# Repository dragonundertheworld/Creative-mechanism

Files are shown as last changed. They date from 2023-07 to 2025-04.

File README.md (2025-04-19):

# Hexapod Carrying Robot

A six‑legged, material‑transporting robot designed and built as part of the “Mechanism Creativity Design & Practice” course at the University of Electronic Science and Technology of China. This project combines a biomimetic four‑bar leg mechanism with a sequential gearbox and a cam‑driven dumping mechanism to achieve stable walking, three‑speed drive, and controlled payload discharge.

---

## Table of Contents

- [Hexapod Carrying Robot](#hexapod-carrying-robot)
  - [Table of Contents](#table-of-contents)
  - [Features](#features)
  - [Mechanical Design](#mechanical-design)
    - [Leg Mechanism](#leg-mechanism)
    - [Tripod Gait Coordination](#tripodgait-coordination)
    - [Sequential Gearbox](#sequential-gearbox)
    - [Payload Dumping Mechanism](#payload-dumping-mechanism)
  - [Performance Specifications](#performance-specifications)
  - [Bill of Materials](#bill-of-materials)
  - [Assembly Instructions](#assembly-instructions)
  - [Motion Simulation \& Testing](#motion-simulation--testing)
  - [Operation Guide](#operation-guide)
  - [Known Issues \& Improvements](#known-issues--improvements)
  - [Future Work](#future-work)
  - [Contact](#contact)

---

## Features

- **Stable Tripod Gait**  
  - Each side consists of front and rear four‑bar linkages, with a centrally driven auxiliary leg to form a three‑point support at all times.  

- **Three‑Speed Drive + Neutral**  
  - Inspired by motorcycle sequential transmissions. Three selectable gear ratios (1:2, 1:1, 2:1) plus neutral for dumping.  

- **Cam‑Driven Dump Mechanism**  
  - When gearbox is in neutral, power is diverted to a cam and follower rod which tilts the payload bucket through a 60° swing.  

- **Modular & Lightweight**  
  - All leg members are assembled from standard aluminum rods and connectors. Custom 3D‑printed dog‑teeth and shafts ensure proper clutch engagement.  

---

## Mechanical Design

### Leg Mechanism

- **Structure**: Two four‑bar linkages per leg (rear crank + rocker driving front rocker), plus an auxiliary “middle” foot bar.  
- **Kinematic Analysis**:  
  - Four‑bar lengths: Crank = 63 mm, Rocker A = 95 mm, Rocker B = 110 mm, Frame = 77 mm (satisfies Grashof condition).  
  - Produces a lifted step height of ~113 mm and horizontal stride of ~146 mm per cycle.  

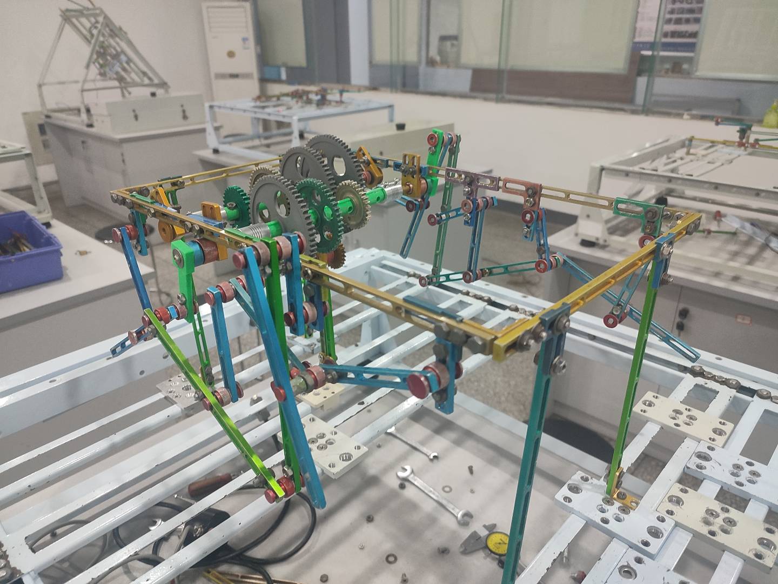
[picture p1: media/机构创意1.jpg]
Leg Mechanism


### Tripod Gait Coordination

- **Phasing**:  
  - Rear cranks on left/right sides set 180° apart.  
  - Middle auxiliary legs mirror each four‑bar’s motion to synchronize three legs in support and three in swing.  
- **Degrees of Freedom**:  
  - F = 3n – 2·Pl – Ph = 1 (single actuation drives one full gait cycle).

### Sequential Gearbox

- **Layout**: Two parallel shafts (input & output), three sliding gears with dog‑teeth collars, one neutral position.  
- **Gear Ratios**:  
  1. First Gear (1:2): 30‑tooth ⟷ 60‑tooth  
  2. Second Gear (1:1): 45‑tooth ⟷ 45‑tooth  
  3. Third Gear (2:1): 60‑tooth ⟷ 30‑tooth  
  4. Neutral: Intermediate slider dog engages secondary shaft’s lower idler gear to drive cam.  

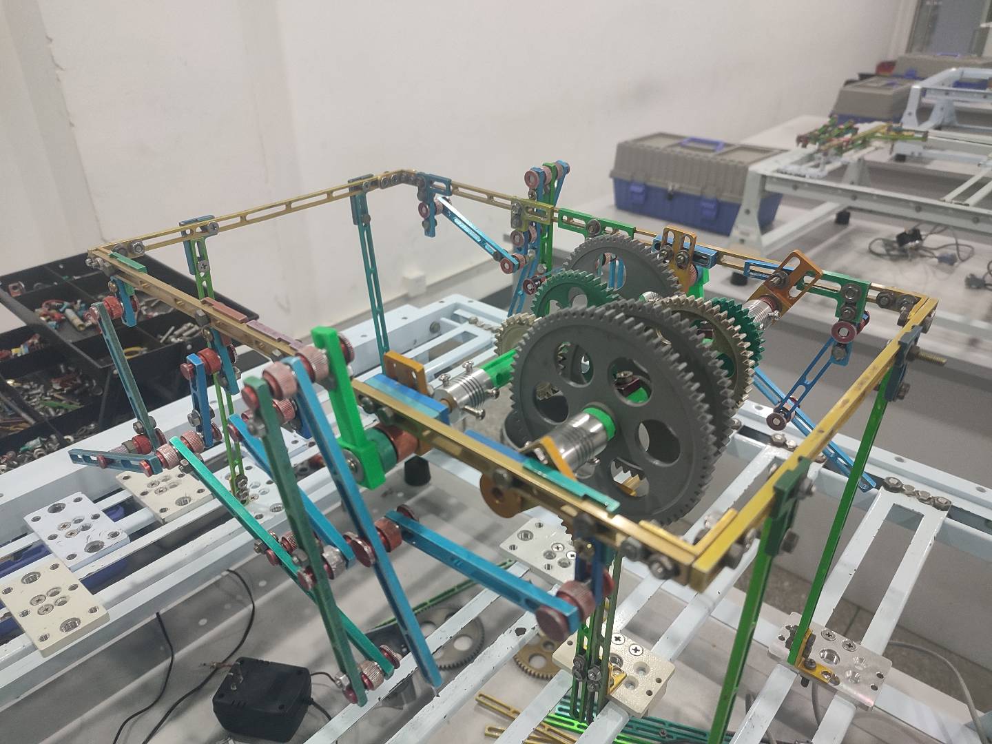
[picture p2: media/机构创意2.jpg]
Gearbox Principle


### Payload Dumping Mechanism

- **Cam‑Follower Design**:  
  - In neutral, power is routed via belt and idler gear to a cam.  
  - A follower rod presses on the cam profile, driving a bucket linkage through 0–60° swing.  
- **Cycle Time**: ~4 s per dump stroke.

---

## Performance Specifications

| Parameter | Value |
|---|---|
| Motor Speed | 30 rpm |
| Leg Cycle Time (30 rpm) | 2.0 s |
| Foot‑Ground Contact Time | 0.6 s |
| Step Length | 146 mm |
| Maximum Lift Height | 113 mm |
| Linear Speeds | 7.3 cm/s (1st), 14.6 cm/s (2nd), 29.2 cm/s (3rd) |
| Dump Angle | 60° |
| Dump Cycle Time | 4 s |

---

## Bill of Materials

| Item | Specification | Qty |
|---|---|-----|
| Aluminum Rods & Connectors | Standard Meccano‑style | 50+ |
| Gears | 30, 45, 60 teeth, m = 1.5 | 6 |
| Custom Dog‑Teeth Collars | 3D‑printed, m = 1.5 | 3 |
| Motor | 30 rpm, 12 V DC | 1 |
| Bearings & Bushings | φ 5–φ 10 mm | 20  |
| Cam & Follower Components | Steel rod & plate | 1 set |
| Buckets & Linkage Plates | Acrylic/PLA | 1 set |
| Fasteners & Limit Nuts | M3–M5 bolts & nuts | 200 |
| Belts & Pulleys | Timing belt, idler pulleys| 1 set |
| Rotary Encoder (optional) | 360 P/R | 2 |

---

## Assembly Instructions

1. **Leg Sub‑Assembly**  
   - Bolt four‑bar linkages together; use limit‑nuts on slotted joints to prevent sliding.  
   - Install auxiliary foot bars at mid‑link hinge points.  
   - Mount front and rear leg pairs symmetrically on left/right frames.  

2. **Gearbox & Motor**  
   - Mount motor to input shaft gear; align dog‑tooth collars on output shaft.  
   - Test each gear position for smooth engagement.  

3. **Dump Mechanism**  
   - Fit cam on lower idler shaft; attach follower rod to bucket pivot.  
   - Route belt from neutral‑position gear to cam pulley.  

4. **Chassis & Frame**  
   - Build a tabletop‑frame fixture for stable walking tests.  
   - Secure all shafts in bearings; leave 0.5–1 mm play for tolerance.  

5. **Final Checks**  
   - Verify free rotation of all joints and gears in each position.  
   - Add washers or shims where necessary to eliminate binding.  

---

## Motion Simulation & Testing

- **Software**: SolidWorks Motion  
- **Test Protocol**:  
  - Drive rear crank at 30 rpm; record foot trajectories and contact time.  
  - Use angle sensors on motor and output shafts to compare theoretical vs. actual speeds.  
- **Results**:  
  - Average driven‑shaft speeds match expected gear ratios within ±5%.  
  - Outliers (3 in 1st gear, 5 in 2nd gear) filtered via 3σ rule; see `data_analysis.py`.

---

## Operation Guide

1. **Power On**: Connect 12 V DC to motor.  
2. **Select Gear**: Slide gearbox collar to desired position (1–2–3 or Neutral).  
3. **Start Walking**: Robot will walk in the selected speed.  
4. **Activate Dump**: Shift to Neutral, wait for cam cycle to complete bucket tilt, then return to walking mode.  
5. **Shutdown**: Shift to Neutral, remove power.

---

## Known Issues & Improvements

- **Joint Play**: Slotted connectors require limit nuts; consider custom printed joints for tighter fit.  
- **Gearbox Space**: Limited room for dog‑teeth—optimize collar length to restore four‑gear capability.  
- **Motor Coupling**: Soldered leads prone to intermittent contact—use a detachable connector.  

---

## Future Work

- **Lightweight Frame**: Replace aluminum rods with CNC‑cut PLA parts to reduce weight and improve precision.  
- **Integrated Clutch**: Implement a one‑way clutch for seamless in‑motion gear shifts.  
- **Autonomous Control**: Add microcontroller and gait‑planning algorithm for untethered operation.  
- **Sensor Fusion**: Integrate IMU and force sensors to adapt foot placement on uneven terrain.

---

## Contact

Project Team: Xuning Gou & Zhihan Cao  
Course Instructor: Prof. Ping Mu  
University of Electronic Science and Technology of China  
Mechanical & Electrical Engineering School  
Email: 1300464438@qq.com

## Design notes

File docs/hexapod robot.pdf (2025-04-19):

摘要

I

摘 要

足式机器人相较于轮式与履带机器人更能适应复杂的地形结构，在军事运 输、抗震救灾、残疾人辅助甚至星际探索等众多领域都有广阔的应用前景。我 们利用杆件设计腿部机构，采用齿轮组进行三档变速，并通过凸轮实现基本的 运载功能。通过课程，我们了解了足式机器人以及变速箱的基本原理，利用四 杆机构得到了较好的足部运动轨迹。

关键字：步行机器人、多足仿生机构、变速机构、运载机器人

目录

II

目 录

第 2 章 机构方案设计 | ？
2.1 方案一设计 | ？
2.2 方案二设计 | ？
2.3 方案比较及定型 | ？
第 3 章 机构设计计算 | ？
3.1 执行件运动设计 | ？
3.2 运动参数设计计算 | ？
3.3 构件参数设计计算 | ？
第 4 章 改进完善设计 | ？
4.1 制约方案实现的原因 | ？
4.2 改进完善 | ？
第 5 章 实验搭建与安装测试 | ？
5.1 机构模型搭建 | ？
5.2 搭建效果及运行结果 | ？
5.3 安装传感器测试 | ？
第 6 章 实验报告与数据分析 | ？
6.1 实验报告 | ？6.2
测试结果 | ？
6.3 数据分析 | ？
结束语 | ？
参考文献 | ？
附 录 | ？

机构创意设计及实践设计报告

3

### 第 1 章 引 言

1.1 工程背景

自从 1959 年第一台工程工业机器人在美国诞生以来，各种用途的机器人便

相继问世。多足仿生机器人由于拥有更高的运动灵活性和对特殊环境的适应性，

一直是研究的热点，在很多特殊的运用场景中都能看到他们的身影。例如，轮式

机器人和履带机器人在较为平稳的环境中速度快，能耗低。但在崎岖的环境中往

往会出现抖动严重的情况，所以在某些对平稳性要求较高的场景中难以达到最佳

效果。足部机器人利用腿部角度和高度的相互配合，可以很大程度的保持自己的

重心位置和平稳性，避免侧翻等危险情况的发生，同时也为路径的最优化选择带

来了更多可能性。

但是由于多足机器人腿部自由度高，也对机体的协调控制带来了巨大的挑

战。在运行过程中必须时刻考虑机体的平稳性，足部的落脚点等诸多因素，导致

它的结构设计和控制算法都尤其复杂。与自然界真实生物的机动性相比，还有很

大的差距。在本次实践中，我们从结构设计入手，得到足式机器人最基本的行走

机构。抛开复杂的控制算法，利用最基本的机械结构使机器人协调运动。虽然这

与最终的仿生机器人还相差甚远，但是却可以为足部构造的研究设计提供重要的

参考价值。

1.2 功能要求及指标

六足机器人又叫蜘蛛机器人，顾名思义，其原理借鉴了自然界中昆虫的运动

原理，机器人的腿部位于身体的两侧，并类似于蚂蚁，在前胸，中胸，后胸各有

一对足。问题的关键，在于两点。一是六条腿之间应该怎样相互配合让整体协调；

二是每条腿部应该如何运动以实现足部末端的运动轨迹。

对腿部之间的协调，我们提出了以下要求：

在整个过程中，机器人的运动尽可能的对称，机体在运行时起伏不能太大，

3

以满足平稳性。

六条腿部的运动效果要尽可能贴近生物的运动姿态。

六条腿之间的配合结构尽可能简洁，以减轻整体的重量。

对每条腿内部的运动，我们提出了以下要求：

腿部在地面支撑的时间应尽可能大于腿部悬空的时间，这有利于整体效率的

提升，对人来说：每一步足部在地面支撑的时间大致为周期的 60%，可以作为参

考。

希望足部的轨迹曲线中，接触地面的一段跨越的水平宽度尽可能大，以提高

行走的速度。

希望足部的轨迹曲线中。悬空时竖直跨越的高度尽可能高，以提高跨越障碍

的能力。

除基本的行走之外，我们希望机器人拥有变速和物料运输的能力。

其中：

变速功能：我们采用齿轮组的配合实现，通过改变齿轮的配合关系，得到不

同的变速比，在本次实验中，我们对机器人设计了四个档位，其中有三个档位用

于速度的调整，另外一个档位用于机器人停下时，物料的装配。

物料运输功能：我们采用基本的凸轮加顶杆的形式实现物料的倾倒动作。只

需要调整顶杆运动的高度，便可以调整物料倾倒的角度。

1.3 发展态势

六足机器人相较于其它多足机器人，有自己独特的优势。相较于两足机器人，

六足机器人更加稳定，不易翻倒。相较于四足机器人，六足机器人又有更大的承

载和工作能力。从国外的情况来看，六足机器人的技术越来越完善，应用场景也

越来越多样化。例如波士顿动力的 RHex 越野六足机器人、NASA 开发研制的

ATHLETE 全地形六足地外探测器、西班牙工业化研究自动所设计的用于排雷的

SILO-6 机器人等。我国的六足机器人虽然发展较晚，但已在迎头追赶国外的技

3

术，例如华中科大设计制造的“4+2”型六足机器人、北京理工大学设计的弓背

蚁机器人、上海交大自主研发的六足滑雪机器人等等。六足机器人正朝着智能化、

实用化、轻量化的方向蓬勃发展，目前适用于恶劣和特殊环境的六足机器人控制

和机械问题还没有得到完全解决，但可以预见未来它们将在人类的生活和工作中

扮演十分重要的角色。

3

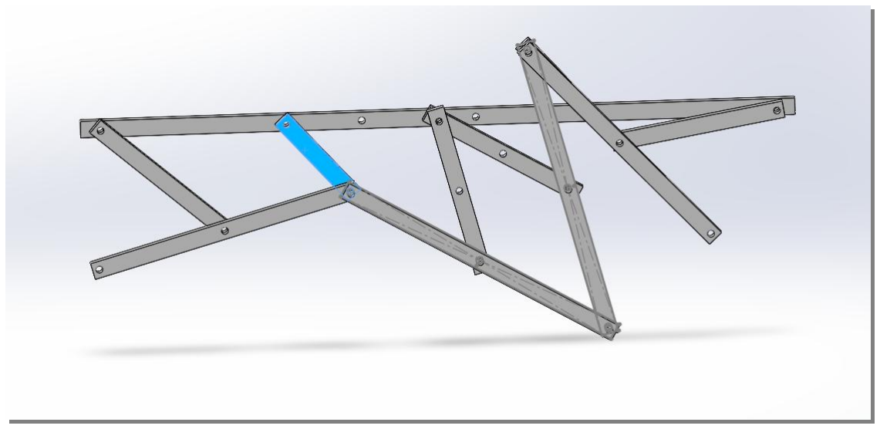
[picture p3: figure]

2

### 第 2 章 机构方案设计

2.1 方案一设计

功能原理：

步行机构

分为左右两条机械腿，每条机械腿由前后两个四连杆机构连接而成，当后面

的连杆机构被驱动时，其会将运动通过连接处同步不同相地传递至前面的连杆机

构，从而实现前后两只脚轮流接触地面。同时中间的连接处也连有一只脚，这种

结构所产生的步态称为三足步态[2]，这样的的设计可以使任意时刻都至少有 3 只

脚同时接触地面，且每个周期内的行进模式完全一致，因此运动更加平稳连贯。

变速机构

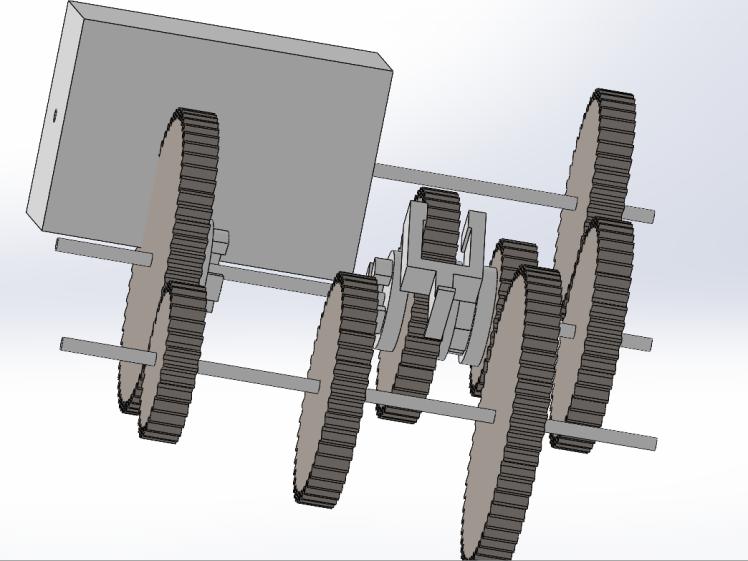
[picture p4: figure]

8

速度档位共有 4 档，分别对应变速比为 1：2，1：1，2：1 的三种齿轮组合

和空挡，通过移动可动齿轮使之与不同齿数的齿轮啮合来改变变速比。

物料运输机构：

当变速机构位于空挡状态下，可动齿轮与铲斗间接驱动齿轮啮合，并通过齿

条将运动传送传递至铲斗直接驱动齿轮，铲斗直接驱动齿轮带动凸轮旋转并通过

顶杆实现铲斗的抬升与下降的往复运动。

仿真搭建图：

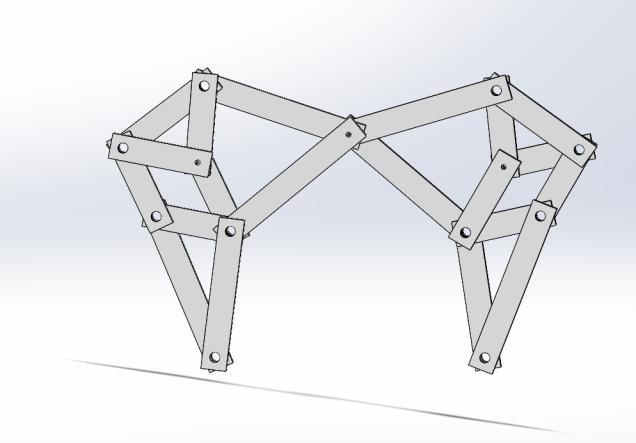
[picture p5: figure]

8

F 计算：

腿部 n=10,pl=13,ph=0, F1=3(n-1)-(2pl+ph)=27-26-0=1

变速箱：以 1：2 档为例：n=9,pl=9,ph=2, F1=3(n-1)-(2pl+ph)=24-20-2=1

物料运输机构：n=7,pl=5,ph=2, F1=3(n-1)-(2pl+ph)=12-10-3=1

2.2 方案二设计

功能原理

Strandbeests 是荷兰动感雕塑艺术家泰奥扬森发明的“风力仿生兽”，本方

案便是仿照其机构并进行设计。其由多条腿组成，每条腿上又分前腿和后腿，二

者通过铰链连接。电机驱动连接处绕轴旋转，运动通过杆件传递至足部。由于存

在多个杆件，其运动较为平稳。

机构简图

F 计算（一条腿）

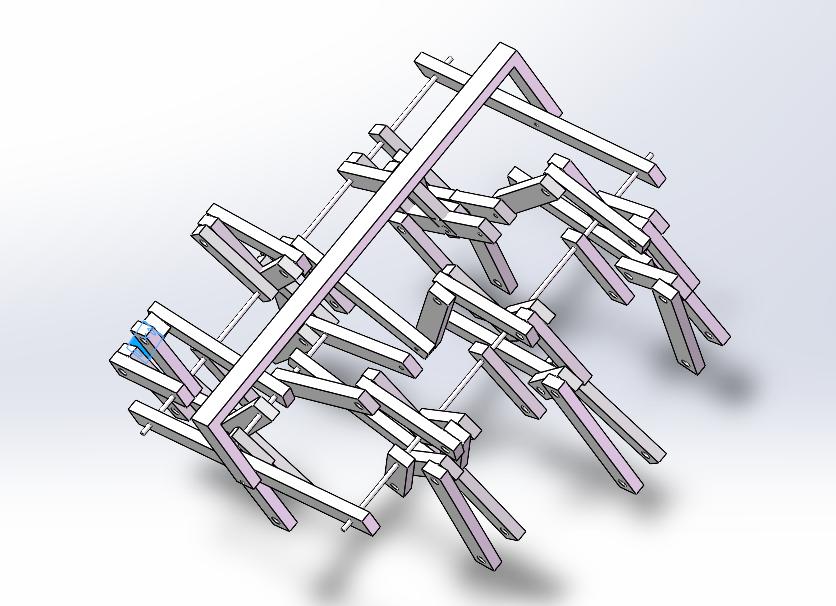
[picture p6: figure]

n=22,pl=31,ph=0, F2=3(n-1)-(2pl+ph)=63-62=1

2.3 方案比较

方案一与方案二两者相比相比，方案二结构更加复杂，具体表现为：①每条

腿所用杆件数量更多②腿数更多③腿之间的配合要求十分紧密。而且中空部分狭

小，放不下变速箱或铲斗等机构。故选择方案一。

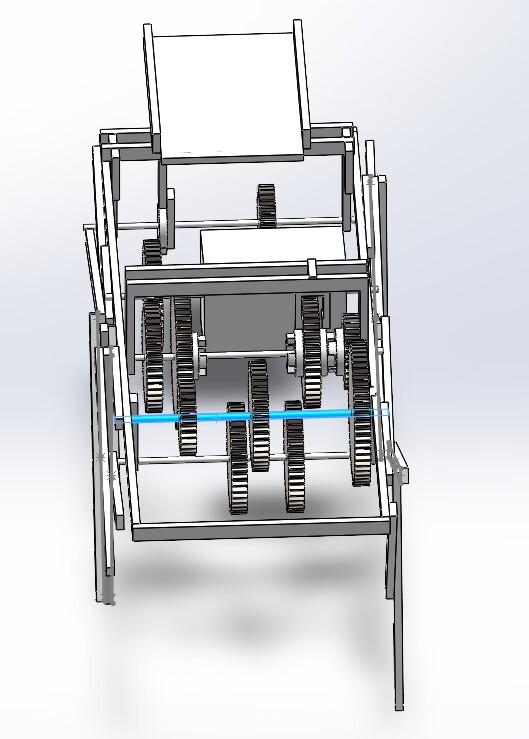
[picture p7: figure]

3

### 第 3 章 机构设计计算

3.1 执行件运动设计

足部和铲斗分别作为机构两个执行件，其中足部由四杆机构中的连杆末端构

成的主足和四杆机构之间的辅助足组成。主足的运动由四杆机构直接控制，而辅

组足则由前后四杆机构的两个曲柄驱动。铲斗则是被连接凸轮的顶杆控制俯仰的

角度，完成倾倒的动作。

如下图所示，在机器人行走的过程中，通过变速箱齿轮之间的狗齿结构，将

动力输出到与腿部曲柄相连的齿轮上，此时铲斗没有动力来源，故不会产生任何

运动。而当机器人到达物料所在地，准备装载物料时，曲柄齿轮将与电动机齿轮

断开并保持不动，而驱动铲斗凸轮的齿轮与电动机齿轮啮合，顶杆被驱动，铲斗

开始做倾倒物料的动作。腿部运动各档位传动比原理图如下：

1：1

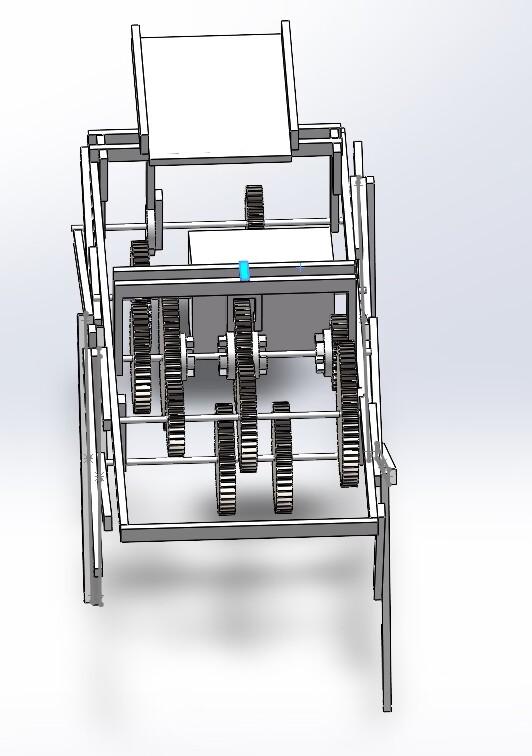
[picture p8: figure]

2：1 | 1：2

铲斗机构传动原理图如下：

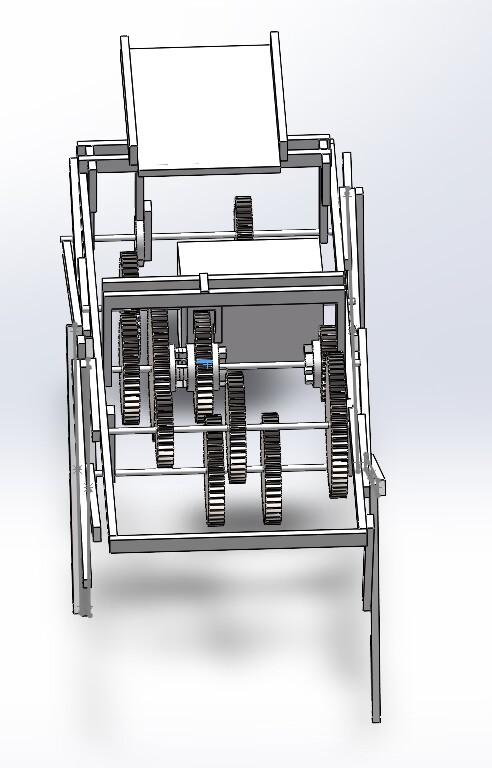
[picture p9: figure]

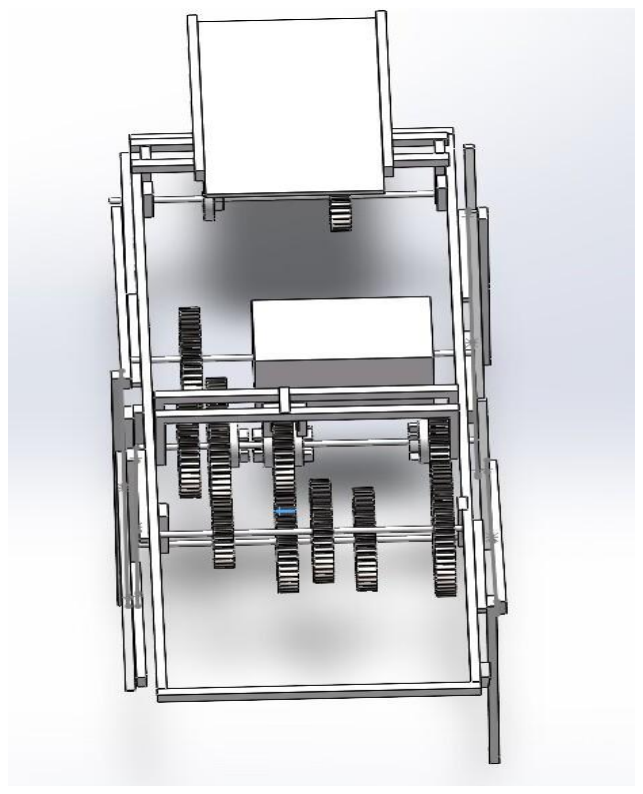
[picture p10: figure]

8

足部的详细运动关系如下：

与马达直接相连的曲柄驱动后腿四杆机构，中间的辅助足由该曲柄直接带

动，辅助足的运动会带动前腿四杆机构的曲柄转动，从而实现单侧三只脚的运动

配合。机器人两侧腿部的结构基本对称，唯一的不同为与原动件直接相连的后腿

曲柄初始角度差为 180 度，在运动中该不变的角度差将使得两侧腿部运动在一个

周期内互补，即对侧的辅助足将永远和本侧的前后主足保持大致平行，而本侧的

主足将与对侧的辅助足保持大致平行，以此得到了三角步态。具体来说：同侧前

后曲柄的角度差始终为 180 度，异侧正对的曲柄的角度差也为 180 度，而对角线

上的曲柄角度一致。我们将中间的辅助足机构看作是对称的两个四杆机构，则六

足机器人可看做是两个四足机器人（①和②）的串联结构，示意图如下：

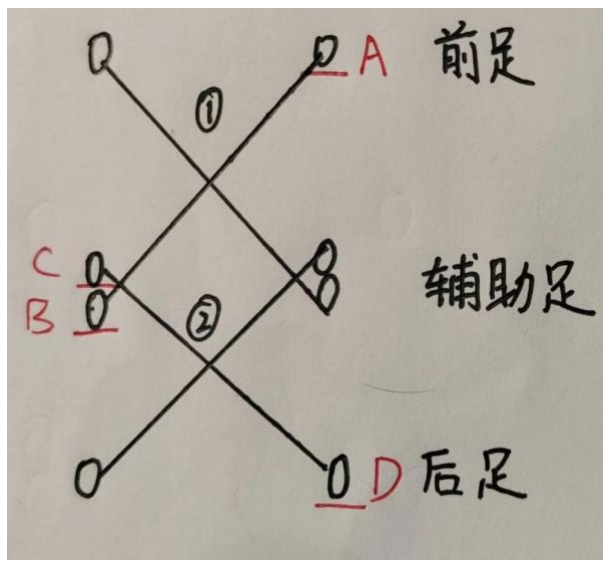
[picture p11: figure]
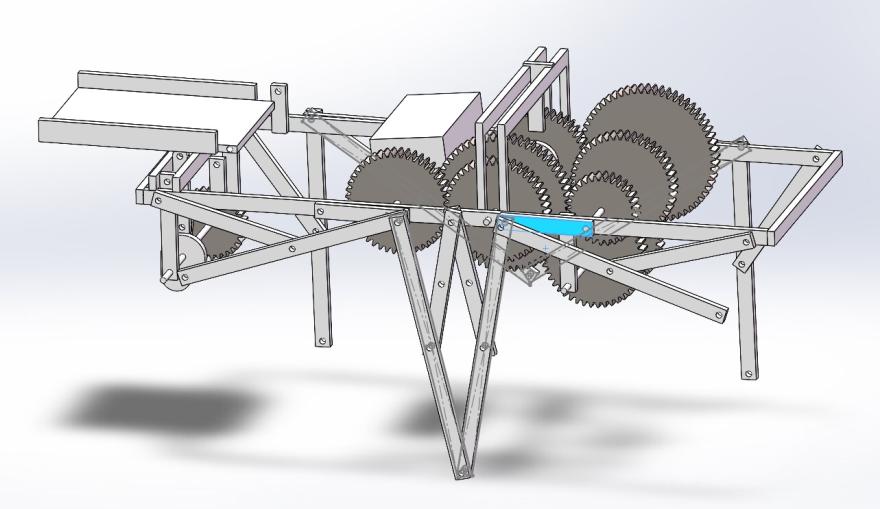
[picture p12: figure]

8

每个四足机器人的运动规律为：若对角线上的前脚 A 先向前迈出，则对角

线上的辅助足中的一半 B 同样向前迈出，两者高度大致相等，而辅助足的两部

分 B 和 C 高度始终相等，另一半和对角线上的后腿 D 同样角度一致高度近似相

等，这样的运动保证了三足步态的稳定性，即呈三角的足部 A、B、C、D 高度

始终近似相等。由于四杆机构的运动特性，电动机每转动一次，单个呈三角关系

足部会经历一次完整的运动轨迹，即 360 度的周期。由于左右两侧曲柄相位差呈

180 度，故而整个机器人在一个周期内实际上前进了两步。

腿部运动一个周期的过程图示例如下：

图一

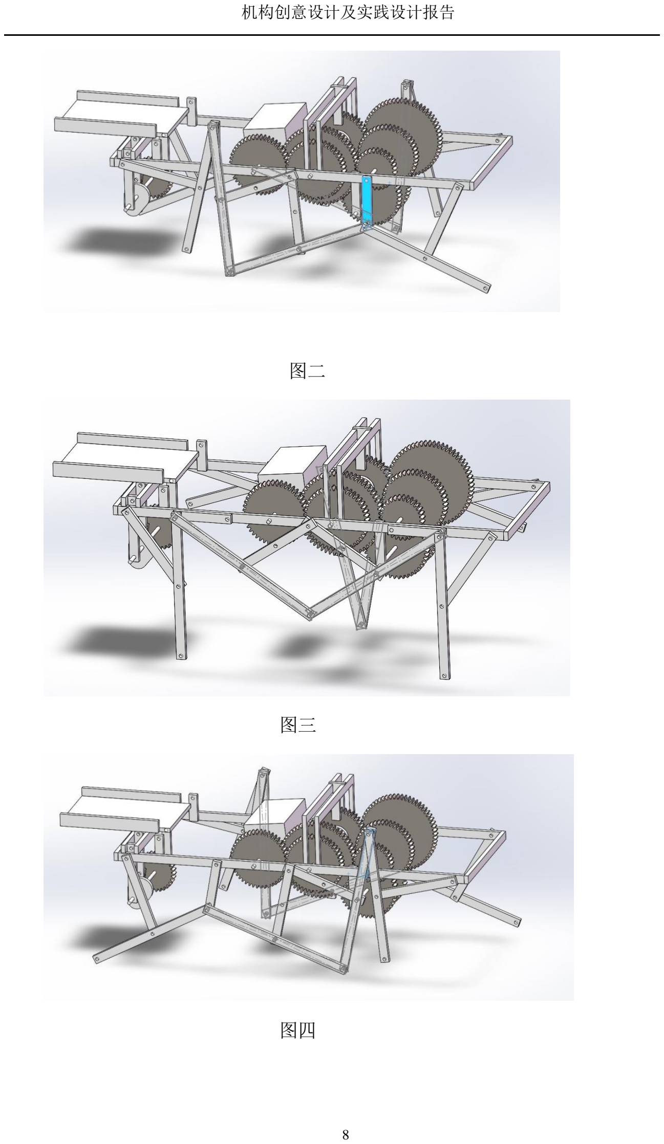
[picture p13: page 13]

8

图二

图三

图四

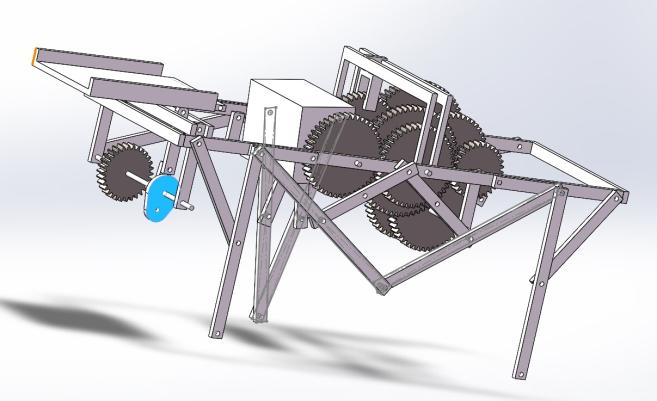
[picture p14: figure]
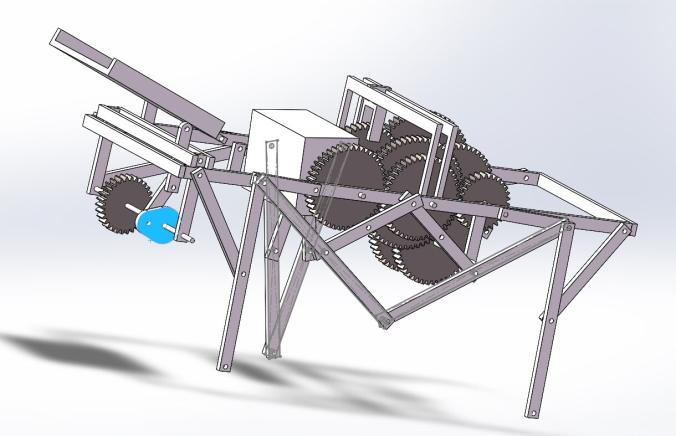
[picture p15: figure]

8

铲斗的详细运动如下：

由于承载物料时，机器人应保持不动，故铲斗的运动关系与腿部相对独立，

铲斗底面与顶杆的顶部相切，顶杆与一连杆相连再与凸轮铰接。电动机经由减速

齿轮、链条传动驱动凸轮旋转，使顶杆做上下往复运动，以此推动铲斗做俯仰的

倾倒动作。

铲斗运动一个周期的过程图示例如下：

图一

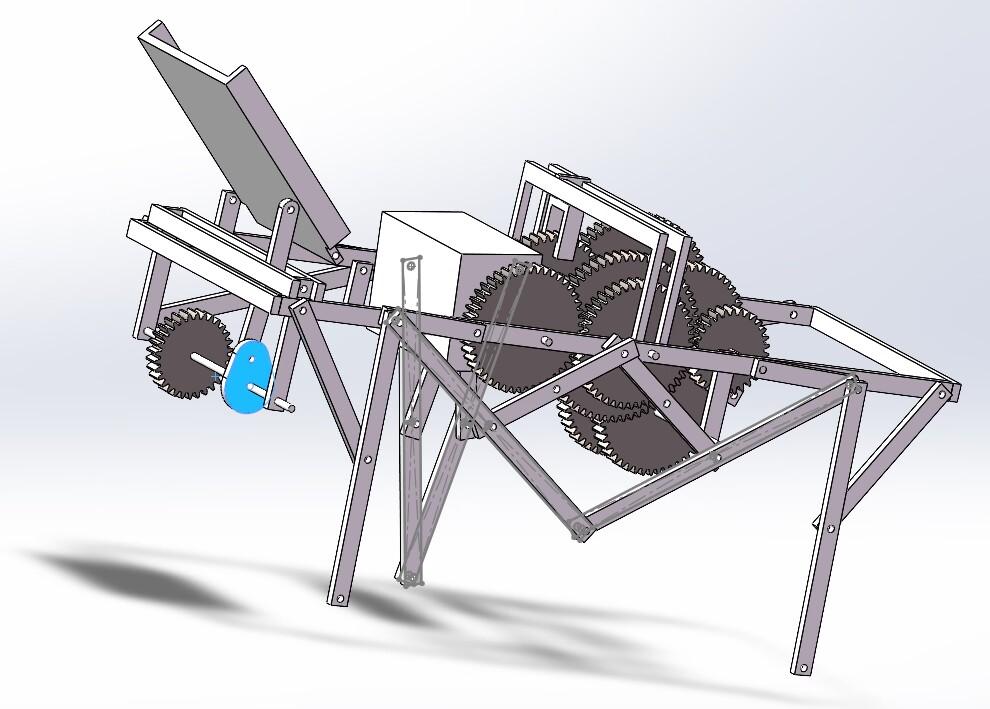
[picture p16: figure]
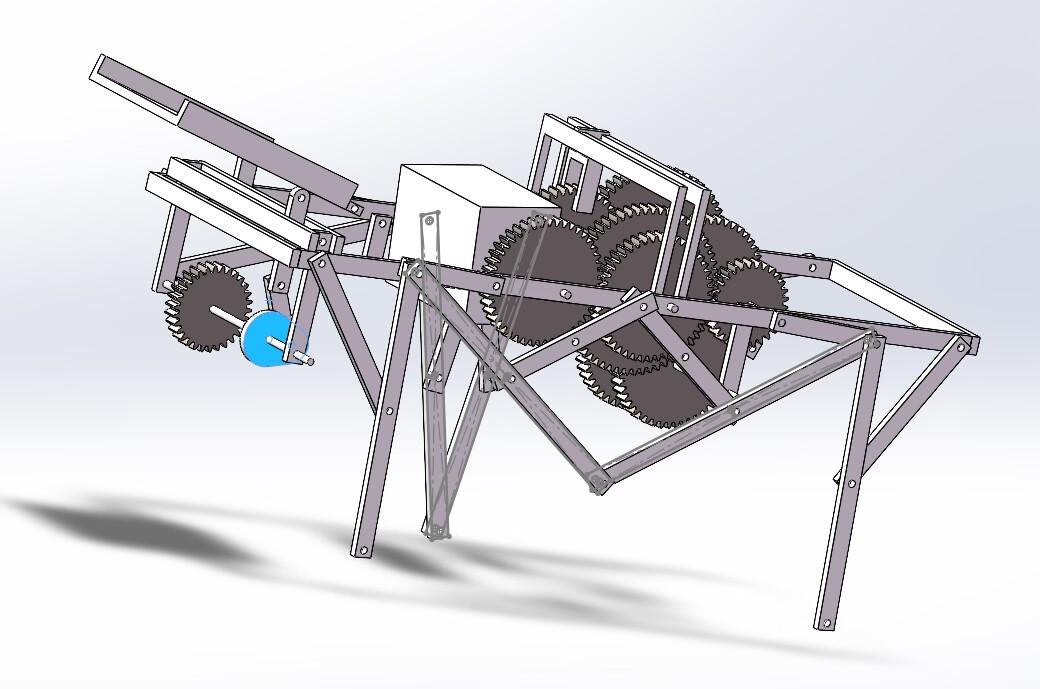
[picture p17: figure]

8

图二

图三

图四

变速功能设计原理如下：

通过查阅大量的变速箱相关资料，我们最终从摩托车的序列变速箱上找

8

到了设计的灵感。我们的变速机构主要由两根轴组成，其中主动轴的末端有一个

齿轮（如下图中间轴最右侧）和电动机驱动的齿轮啮合，该齿轮和主动轴固定在

一起，并且直接带动主动轴旋转。主动轴上还有用于调速的三个齿轮，左右两边

的齿轮和轴之间可以发生相对转动，但是无法沿轴平动。中间的齿轮可以沿轴左

右平动，但是通过键和轴连接，故无法相对轴发生转动。从动轴上的三个齿轮均

和轴固定相连，既无法和轴相对转动，也无法在轴上左右平动。当主动轴上中间

齿轮和从动轴的中间齿轮啮合时，此时传动的顺序为：动力由主动轴中间齿轮直

接到从动轴中间齿轮，为二档速度。当主动轮上中间齿轮向左平动，通过狗齿和

左边齿轮固定时，此时左边齿轮和轴一起转动，并将动力传递给从动轴上的左边

齿轮，此时传动的顺序为：动力由主动轴中间齿轮传递给主动轴左边齿轮再传递

给从动轴左边齿轮，为三档速度。同理，当主动轮上中间齿轮向右平动，通过狗

齿和右边齿轮固定时，此时传动的顺序为：动力由主动轴中间齿轮传递给主动轴

右边齿轮再传递给从动轴右边齿轮，得到一档速度。在设计中我们单独安装了一

根轴在主动轴和从动轴下方，并在轴上固定了一个齿轮，当主动轴中间齿轮和该

轴上齿轮啮合时，可进一步通过皮带装置带动物料装置运动。

3.2 机构运动参数设计计算

将实际组合机构通过 solidworks 运动仿真，根据已有电动机仿真得到的腿部

运动周期时长如表格所示：

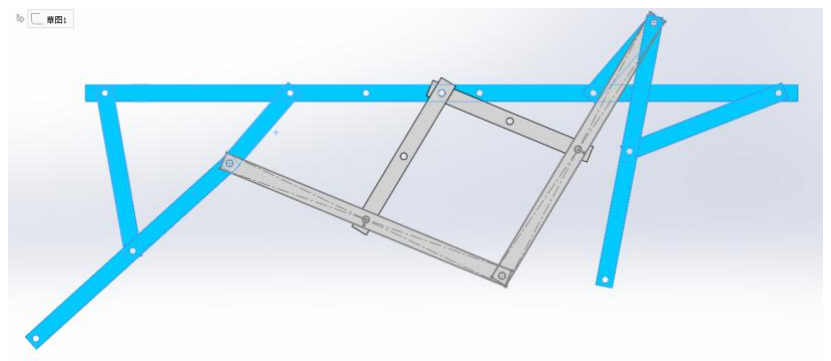
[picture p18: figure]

8

电机转速 \rpm | 完整一步所用时间\s | 每步中接触地面所用时间 \s
10 | 4.3 | 1
15 | 3.4 | 1.1
30 | 2 | 0.6

经过对比我们最终选择了转速为 30rpm 的电机，我们将步长定义为一只脚

接触地面到它离开地面的过程中，机架向前移动的距离。则此时测出机器人步长

为 146mm，腿部每次抬起的最大高度为 113mm 左右，此时运动速度分为三档各

为：7.3cm/s、14.6cm/s 和 29.2cm/s。

对于铲斗机构：铲斗一次倾倒物料的时间为 4s，仰起的角度为 60 度，完全

放下时的角度为 0 度。

3.3 构件参数设计计算

腿部杆长条件：

腿部为两个四杆机构(曲柄-摇杆)组成，如下图所示

而四杆机构存在杆长条件、死点，其中杆长条件为

（1）

我们四个杆的长度分别是 56，110，95，77,而 56+110<95+77，符合杆长条

件。

辅助足构件计算如下：

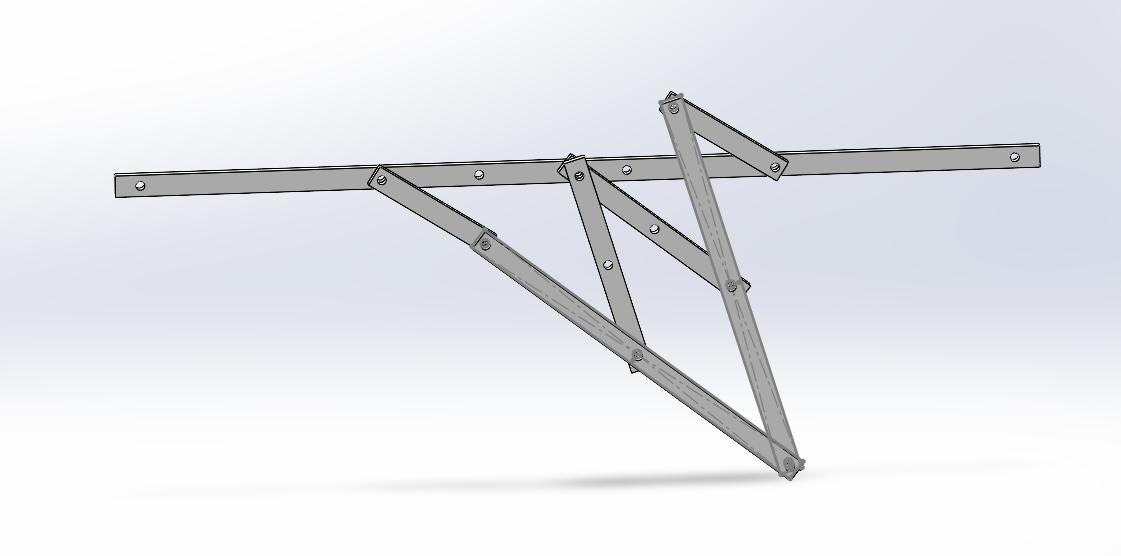
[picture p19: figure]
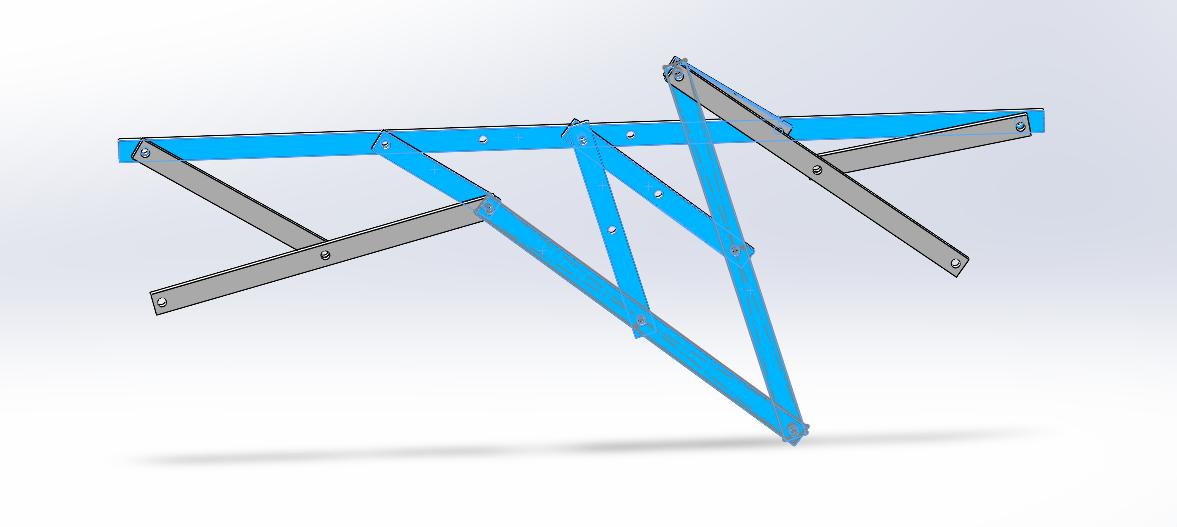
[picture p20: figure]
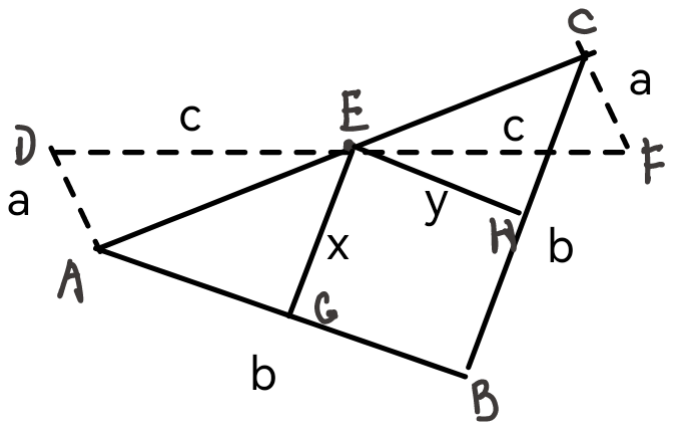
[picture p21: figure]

8

已知两个曲柄呈 180°，AD 平行且等于 CF、AB=BC=b、AB//EH 且 EG//BC，

我们需要求 H、G 的位置和 EH、EG 的长度。

那么此时▲AED≌▲CEF，E 为 AC 中点，所以 EH、EG 为中位线，即 H、

G 分别为 BC、AB 中点，EH=EG=1/2b。

变速结构我们采用的变速比分别为 0.5、1、2，根据齿轮的变速比公式：

8

（2）

设第一级齿轮的齿数为 n，则还需要 2n，n 和 0.5n 的齿轮，由于实验室中的

齿轮齿数为 25~70 并按 5 递增，我们只有唯一一种方案可以选择即为齿数分别为

30、45、60 的齿轮。由于变速箱的结构主要由平行的两根轴以及轴上的齿轮组

成，为了让齿轮组都能够正常啮合到一起，除模数相等外，我们还需要让两两齿

轮的分度圆半径之和相等。由齿轮模数与分度圆直径公式：

（3）

可得 D1=M1*Z1=1.5*30=45,同理 D2=67.5，D3=90。

满足 D2+D2=D1+D3=D3+D1,故可以正常啮合。

凸轮尺寸计算已知铲斗的相对凸轮轴的位置如图所示：

由几何关系可得：凸轮半径约为 a/2tanΘ。

根据实验室已有的杆件尺寸，我们进行了一系列试验，试验流程如下：

为了实现我们的技术指标，经过多次尝试最终得到了最优机构，以下列举出

部分试错机构：

错

不能动组合 | 新的组合 | 可动组合

8

机 构 名 称

片 及 尺 寸 参 数

题 | 该机构无法运动 | 可以达到 60%，但跨障碍 能力弱 | 该机构留给齿轮和电机的 安装空间较小
题 图 片 | \ | 黑色线为足部轨迹，可见 轨迹顶端与底端高度差较小 | 实际装配体，可见齿轮较拥 挤且没有空间放置电机

最终我们选择了这一版方案

尺寸：

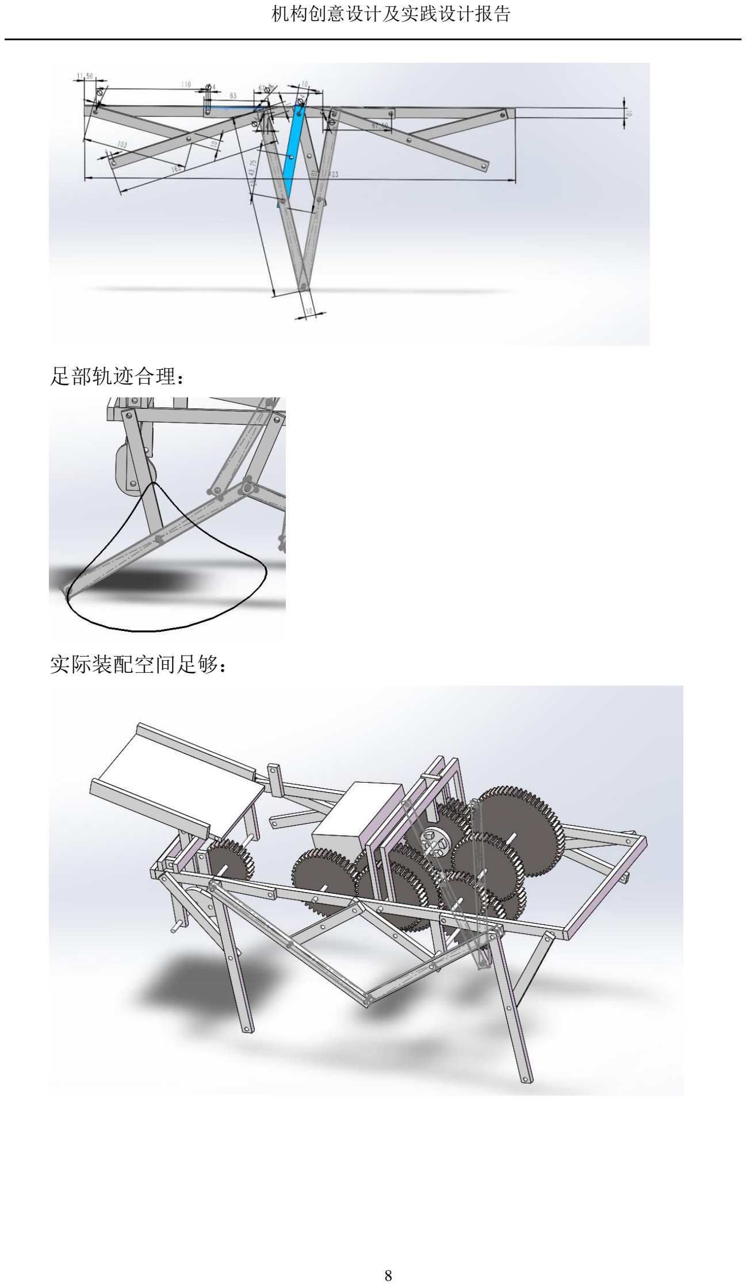
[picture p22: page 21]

8

足部轨迹合理：

实际装配空间足够：

8

### 第 4 章 改进完善设计

4.1 制约方案实现的原因

①杆件缺少限位

画图时每个杆件只有 2-3 个孔，杆件之间计划直接通过螺钉连接；实际杆件

中间为直槽口，需通过活动铰链连接，若不加限位铰链会在杆件的直槽口中移动。

②关节处冗余空间少

由于装配存在误差，若严格按照计划图纸安装并严格限位则机器人会卡死

③地面行走阻力过大

原本计划在桌面或地面安装机器人便于观察其行走姿态，实际发现行走时阻

力大、不稳定且难以安装

④固定铰链层数高

⑤缺少安装齿轮的长轴、曲柄的尺寸不合适、缺少狗齿、狗齿无法安装在小

齿轮上

⑥电机接触不良
4.2 改进完善

对于①需要螺栓螺母进行限位

对于②限位时需留出冗余空间

对于③选择在桌面上搭建机架以便于安装

对于④垫上 2 层杆件

对于⑤自己设计并 3D 打印出了想要的轴、曲柄、狗齿、小齿轮，再用锉刀

调整尺寸

对于⑥通过焊接修复导线与电机的连接

机构简图无变化

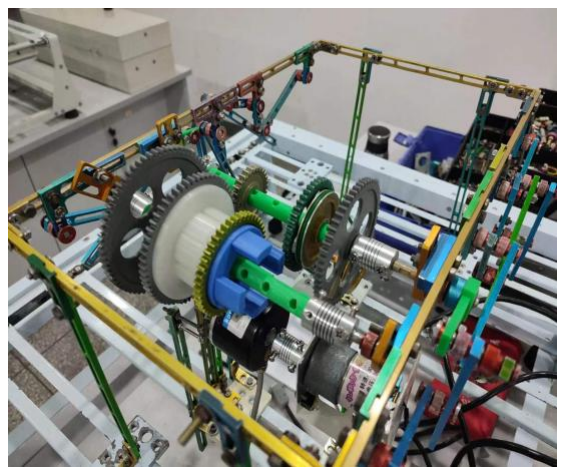
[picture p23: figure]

8

### 第 5 章 实验搭建与安装测试

5.1 机构模型搭建

①杆件缺少限位

画图时每个杆件只有 2-3 个孔，杆件之间计划直接通过螺钉连接；实际杆件

中间为直槽口，需通过活动铰链连接，若不加限位铰链会在杆件的直槽口中移动，

需要螺栓螺母进行限位。

②关节处冗余空间少

由于装配存在误差，若严格按照计划图纸安装并严格限位则机器人会卡死，

限位时需留出冗余空间。

③地面行走阻力过大

原本计划在桌面或地面安装机器人便于观察其行走姿态，实际发现行走时阻

力大、不稳定且难以安装，于是我们选择在桌面上搭建机架以便于安装。

④固定铰链层数高

垫上 2 层杆件以便于固定。
5.2 搭建效果及运行结果

搭建效果：基本按照计划中的杆长搭建，如图

运行结果：按照预期的轨迹运动，但运行不够流畅

8

5.3 传感器安装测试

待测物理量：主动轴的旋转速度和电机输入的旋转速度

传感器选择：角位移传感器

传感器安装方式：由于主动轴两端无法伸出机架，需通过同步带将主动轴的

角位移引出到外部的同步轮上。电动机一端直接接入传感器。

测试方式：用角位移传感器直接测外部同步轮的速度

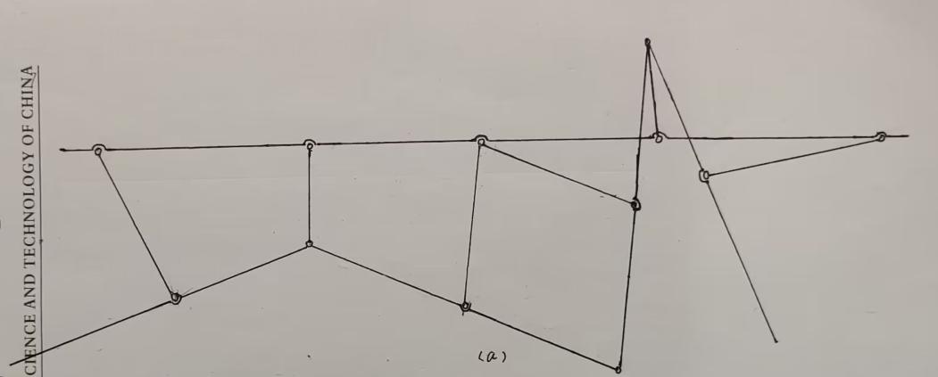
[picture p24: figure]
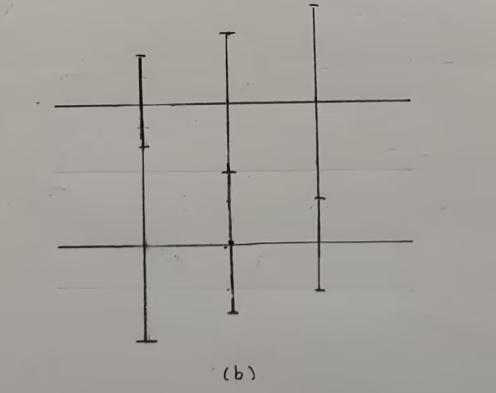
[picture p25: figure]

8

### 第 6 章 实验报告及数据分析

6.1 实验报告

1．机构简图（比例：1:4）
腿部机构简图如（a）所示：

变速机构简图如（b）所示：

8

2．机构工作原理
腿部机构由前后两个四杆机构和中间的辅助脚机构构成，左右两侧腿部运动

时为三足步态以保持平稳。通过仿真得到了较好的杆件末端的足部轨迹，使得机

器人拥有较大的前进速度和抬脚高度。

变速机构采用了序列变速箱的基本原理，利用不同齿轮的狗齿配合，以达到

齿轮的不同啮合效果，由此获得三档速度。

详细原理描述见 3.1。

3．实物模型参数

构件名称 | 参数 | 构件名称 | 参数 | 构件名称 | 参数
机架长杆 | 423mm | 四杆腿部 | 173mm | 辅助足摇杆 | 103mm
机架宽杆 | 253mm | 四杆摇杆 | 103mm | 辅助足腿部 | 183mm
四杆机架 | 223mm | 四杆曲柄 | 63mm | 轴长 | 165mm
齿轮 1 | 45 齿 | 齿轮 2 | 30 齿 | 齿轮 3 | 60 齿
电动机 | 30rpm
4. 机构自由度计算：F=3n－2Pl－Ph

机构共有 20 个活动构件，28 个低副，3 个高副

F=3*20-2*28-3=1

运动结论：

5.运动模拟：在腿部轴处用电动机驱动，模拟蚂蚁行走的过程。

6.传感器安装测试：在电动机处安装角速度传感器，保证传感器外壳固定，

测试电动机输入轴的转速；在腿部轴处安装带轮然后通过带传出到外部角速度传

感器，保证传动过程的平稳，测试输出轴的角速度；

7. 指出在机构中自己的创新之处。

机器人的六足结构采用了不同于传统的全新方式，使用四杆机构为基础，

使得结构更加简洁。变速箱借鉴了摩托车序列变速箱的原理，可实现三档变速。

8．指出机构的不足之处

由于采用杆件连接很难精准把握每一个杆的尺寸，并且铰链的配合不稳，

8

经常出现脱落的现象，导致机器人在运动过程中出现了行走不稳和抖动的问题。

同时由于 3d 打印件轴存在较大的尺寸误差，齿轮的啮合不紧密，需要外部力量

压紧。

9. 进一步改进的设想

由于机构狗齿过长，导致最终轴上只能容纳两个齿轮，实现了两档变速，可

以将狗齿尺寸进一步缩短调整，以实现预期功能。同时可以将变速机构做进一步

优化，做出机架或者容器，使用操纵杆移动齿轮，避免人手和齿轮的接触。可以

采用离合装置，以实现运动过程中的变速功能。对机架和腿部可以采用 PLA 打

印件以减轻整体的重量，并减小尺寸误差，使运行更加流畅。对于轴这样加大难

度大的零件，可以使用更加精确的打印器材。
6.2 测试数据

### 一档运动测试分析仪实验报告

主动件角位置 （ °） | 从动件角位置 （ ° ） | 从动件角速 度（rad/s） | 从动件角加速 度（rad/s2）
140.500000 | -291.000000 | -0.000319 | -0.004301
261.500000 | -334.500000 | -1.583039 | -1.106804
381.000000 | -10.500000 | 12.561680 | -337.968981
498.500000 | -55.000000 | -1.214529 | -11.994658
620.000000 | -107.000000 | -1.826635 | 1.500102
739.000000 | -156.000000 | -2.022114 | 5.698058
858.000000 | -200.000000 | -1.303155 | -4.725825
977.500000 | -240.500000 | -1.111317 | -8.727698

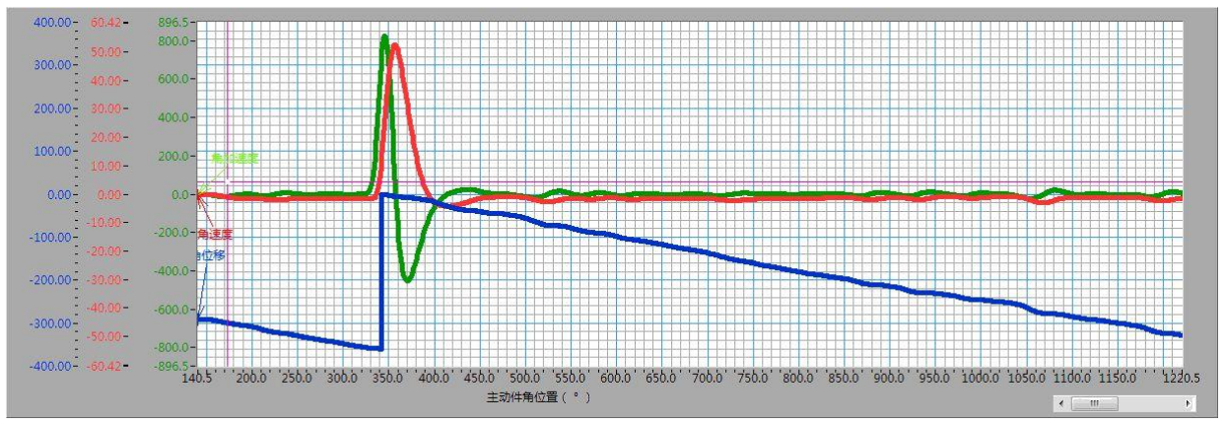
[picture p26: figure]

8

1096.000000 | -283.500000 | -1.216962 | 4.439824
1214.000000 | -326.000000 | -1.667803 | 11.314908
1336.000000 | -12.000000 | 18.065426 | -394.309853
1454.500000 | -53.500000 | -1.114686 | 3.631922
1572.500000 | -98.500000 | -1.483755 | 1.915476
1692.500000 | -141.000000 | -1.438855 | -2.974068
1812.000000 | -190.500000 | -1.783155 | 0.239640
1930.000000 | -233.000000 | -1.605825 | -8.994381
2048.000000 | -261.000000 | -0.707923 | -3.577622
2167.500000 | -303.500000 | -1.344875 | -0.506047
2286.000000 | -351.500000 | -1.789305 | 4.837253
2406.500000 | -27.500000 | -1.608325 | 17.088664
0.000000 | 0.000000 | 0.000000 | 0.000000

8

## 二档运动测试分析仪实验报告

主动件角位置 （ °） | 从动件角位置 （ ° ） | 从动件 角速 度（rad/s） | 从动件角加速 度（rad/s2）
281.500000 | -317.500000 | -0.002835 | -0.044324
404.000000 | -51.500000 | -5.462295 | -70.451795
522.000000 | -124.500000 | -4.402728 | 11.869728
636.000000 | -176.000000 | -2.237097 | -65.223016
760.500000 | -296.500000 | -1.730729 | 8.890794
881.000000 | -35.000000 | 16.618343 | -381.710770
1002.500000 | -108.500000 | -2.278690 | -42.705569
1123.500000 | -221.000000 | -7.054229 | 33.990897
1243.500000 | -302.000000 | -2.007001 | 7.472740
1365.000000 | -32.500000 | 20.414758 | -422.844767
1465.000000 | -94.000000 | -0.297866 | 3.090893
1570.500000 | -153.500000 | -1.637287 | 2.389527
1694.500000 | -263.000000 | -2.923498 | -16.160474
1818.000000 | -359.000000 | 4.057158 | 593.781428
1939.000000 | -98.500000 | -1.997066 | 32.150135

8

2058.000000 | -172.500000 | -1.645832 | -9.611120
2184.000000 | -296.000000 | -2.491402 | -0.766049
2305.500000 | -31.500000 | 34.898345 | -447.289223
2429.000000 | -107.000000 | -1.417731 | 16.095863
2548.500000 | -177.500000 | -1.670719 | -6.564856
0.000000 | 0.000000 | 0.000000 | 0.000000

### （图像数据丢失）

6.3 测试数据分析

表一、表二分别为机器人在一档、二档速度下的测试数据，主动件为电机，

从动件为驱动轴。首先是数据的平稳性：由图像可以看出整体较稳，某些位置波

动较大，由数据分析可以得到一档数据有 3 个离群值，二档有 5 个，二档较一档

更不平稳；其次是数据的大小分析，对这两组数据分别剔除正值，再根据 3σ原

则剔除离群值并对剩余数据取均值，得到一档、二档的驱动轴的角速度的均值分

别为-1.379032、-2.453562，相差约 1.8 倍，接近 2 倍，符合实验预期。

python 代码如下：

import pandas as pd

import numpy as np

data1=np.array([-0.000319,-1.583039,12.561680,-1.214529,-1.826635,-2.022114

,-1.303155,-1.111317,-1.216962,-1.667803,18.065426,-1.114686,-1.483755,-1.43885

5,-1.783155,-1.605825,-0.707923,-1.344875,-1.789305,-1.608325,0.000000])

data2=np.array([-0.002835,-5.462295,-4.402728,-2.237097,-1.730729,16.61834

3,-2.278690,-7.054229,-2.007001,20.414758,-0.297866,-1.637287,-2.923498,4.05715

8,-1.997066,-1.645832,-2.491402,34.898345,-1.417731,-1.670719,0.000000])

df1 = pd.DataFrame(data1,columns=["value"])

8

df2 = pd.DataFrame(data2,columns=["value"])

pro_df1 = df1[df1['value']<0]

pro_df2 = df2[df2['value']<0]

mean1 = pro_df1['value'].mean()

mean2 = pro_df2['value'].mean()

sigma1 = pro_df1['value'].std()

sigma2 = pro_df2['value'].std()

final_mean1=pro_df1[(pro_df1['value']<(mean1+3*sigma1))&(pro_df1['value']>

(mean1-3*sigma1))].mean()

final_mean2=pro_df2[(pro_df2['value']<(mean2+3*sigma2))&(pro_df2['value']>

(mean2-3*sigma2))].mean()

print(" | 一 | 档 | 数 | 据 | 的 | 离 | 群 | 值 | 有 | {} | 个

".format(df1.count().value-pro_df1.count().value))

print(" | 二 | 档 | 数 | 据 | 的 | 离 | 群 | 值 | 有 | {} | 个

".format(df2.count().value-pro_df2.count().value))

print("二者均值分别为{},{}".format(final_mean1.value,final_mean2.value))

print("相差{}倍".format(final_mean2.value/final_mean1.value))运行结果如图：

8

### 结束语

通过本次实验，我们基本上实现了六足机器人的设计和搭建，虽然在方案实

施的过程中我们遭遇了很多问题，在最终都一一进行了解决。尽管过程是非常艰

辛的，但是我们锻炼了多方面的能力，例如：仿真软件的使用能力，专业知识的

应用能力，随机应变的思维能力，动手能力，合作能力等都得到了巨大的提升。

在未来，随着专业知识的进一步加深，我们可以将课程中设计的六足机器人进一

步的改进。并将它的功能和实际应用场景相结合，做出真正有用的机器人。

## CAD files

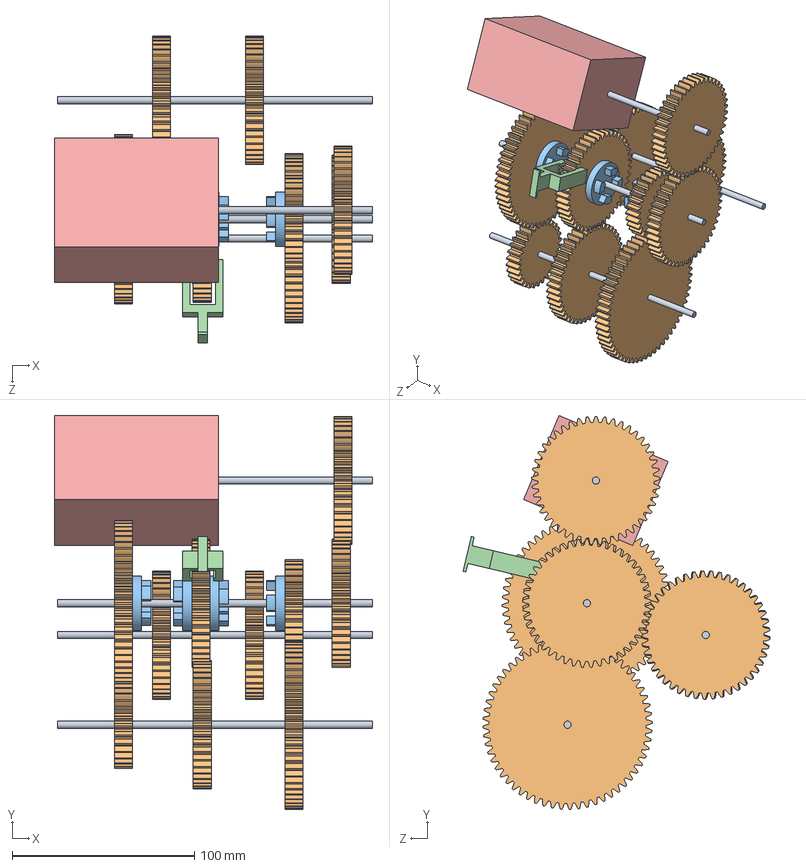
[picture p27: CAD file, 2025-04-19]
assets/变速器.SLDASM
174.6 x 216.1 x 168.4 mm
齿轮轴 x 4
spur gear_gb x 10
狗齿 x 4
拨动杆
电机

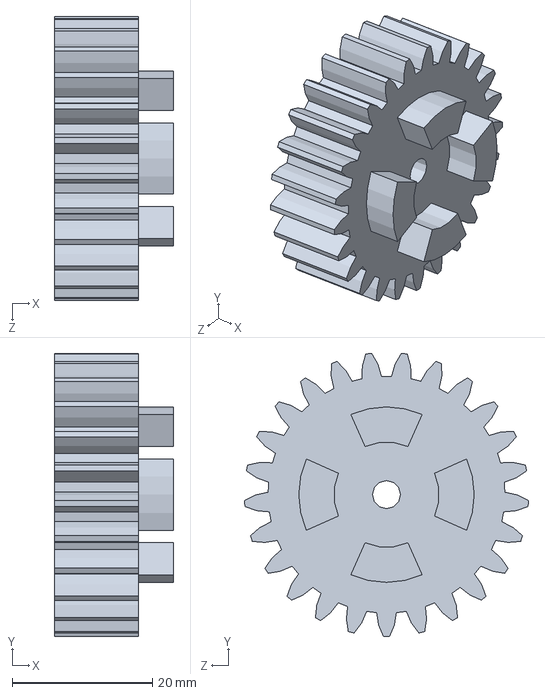
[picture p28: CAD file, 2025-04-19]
assets/狗齿预备齿轮.SLDPRT
17.0 x 40.4 x 40.5 mm

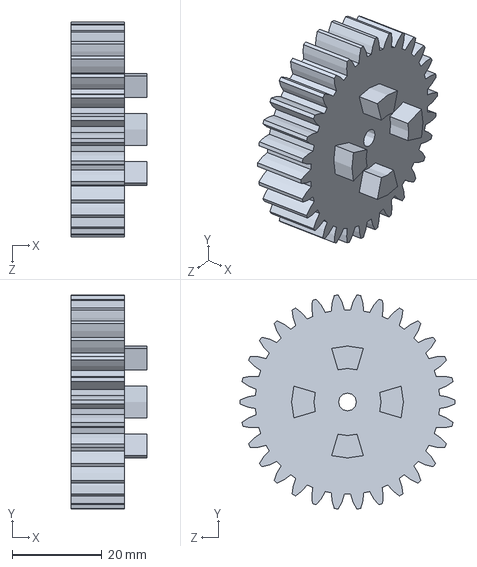
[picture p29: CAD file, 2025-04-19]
assets/狗齿齿轮30齿（从动）.SLDPRT
17.0 x 47.8 x 48.0 mm

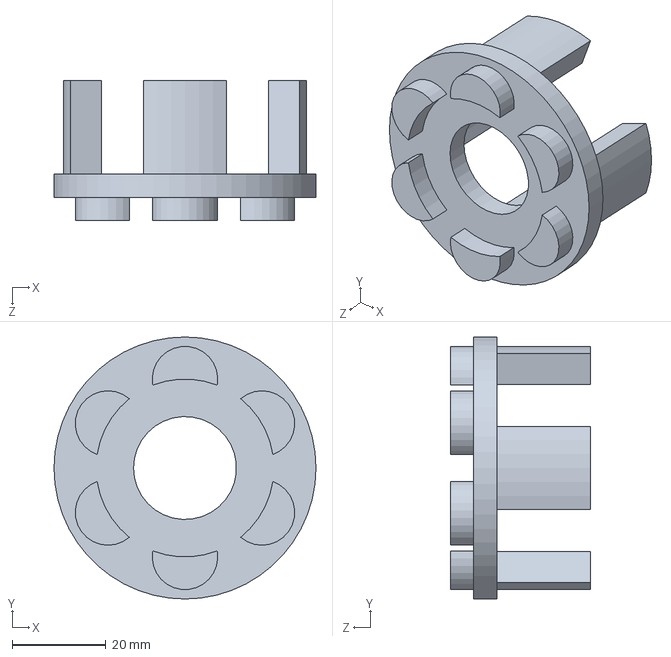
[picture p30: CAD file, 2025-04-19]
assets/狗齿45max.SLDPRT
56.0 x 56.0 x 30.0 mm

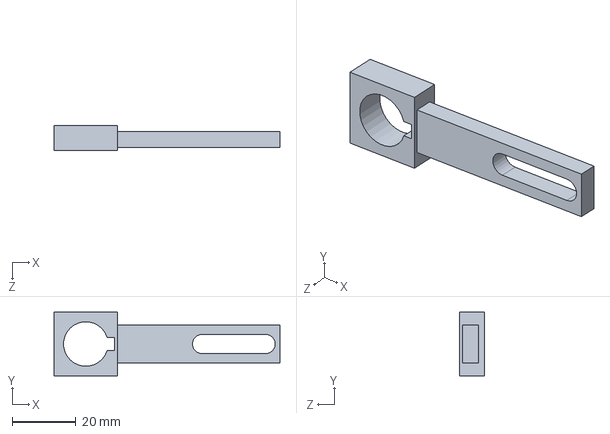
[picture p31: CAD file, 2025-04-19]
assets/3D摇杆.SLDPRT
71.0 x 20.0 x 8.00 mm

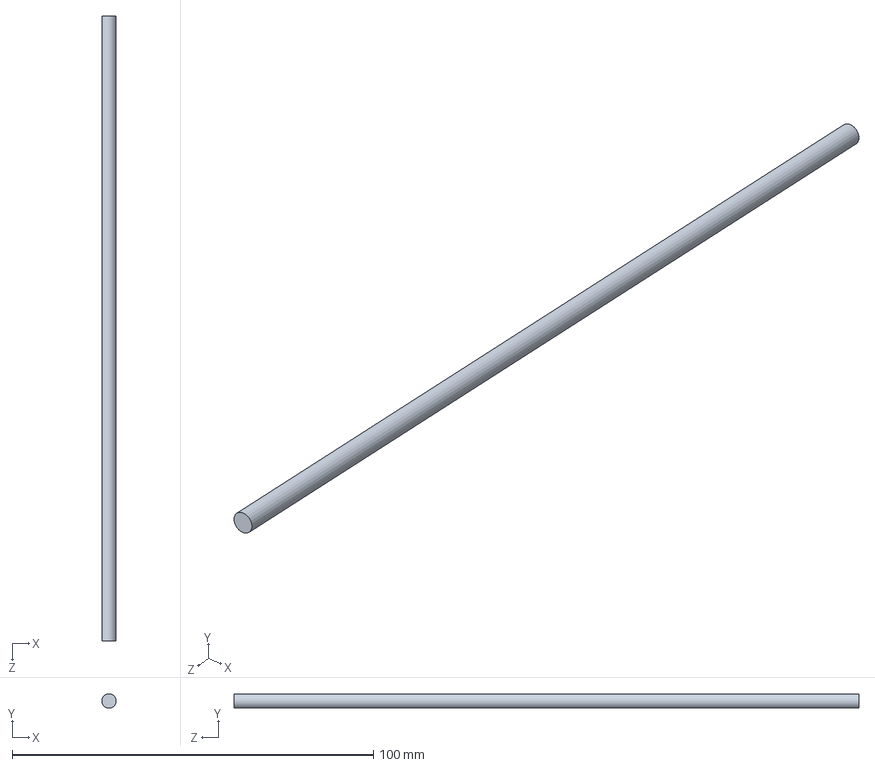
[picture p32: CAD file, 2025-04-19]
assets/齿轮轴.SLDPRT
4.00 x 4.00 x 173.0 mm

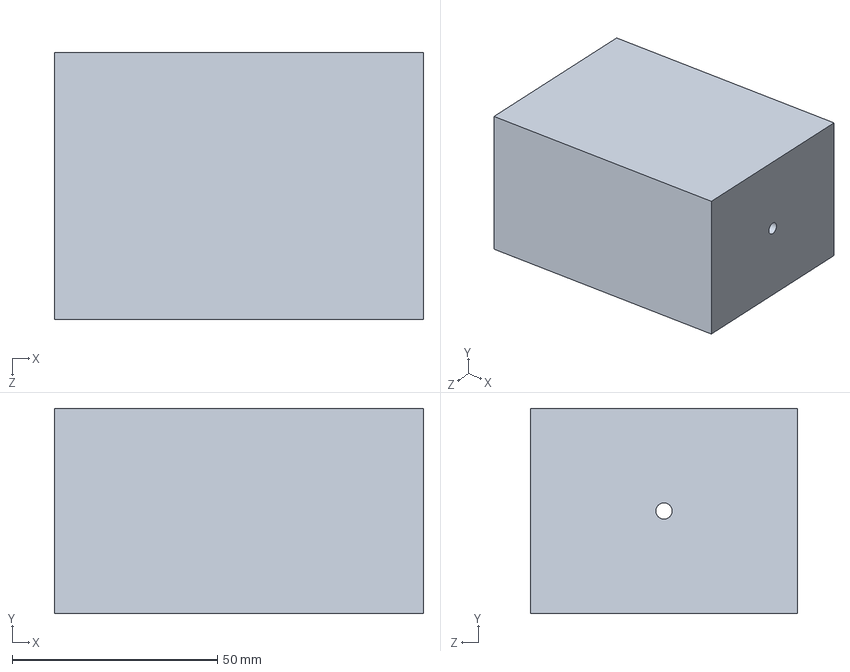
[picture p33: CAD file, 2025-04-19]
assets/电机.SLDPRT
90.0 x 50.0 x 65.0 mm

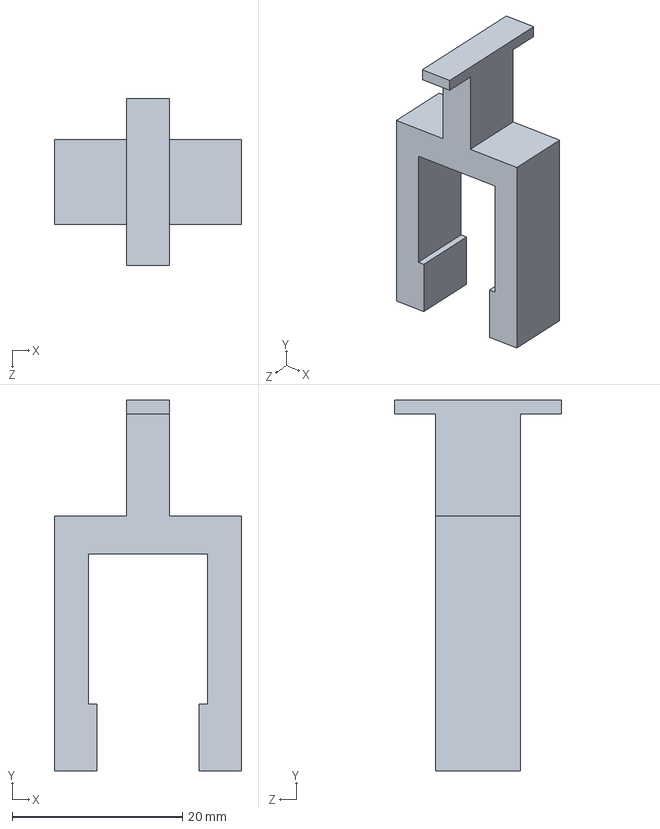
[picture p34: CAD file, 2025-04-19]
assets/拨动杆.SLDPRT
22.0 x 43.6 x 19.6 mm

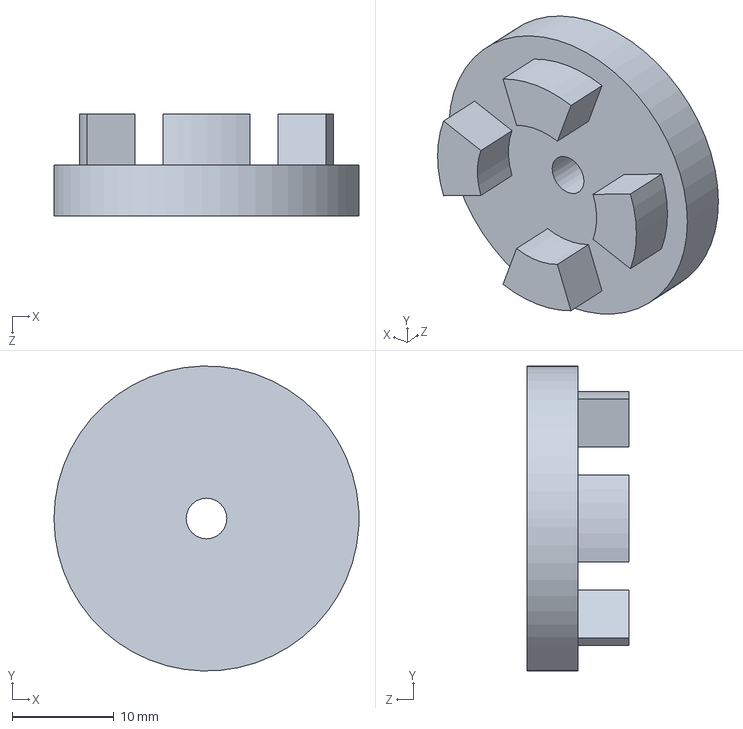
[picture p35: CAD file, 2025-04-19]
assets/狗齿.SLDPRT
30.0 x 30.0 x 10.0 mm

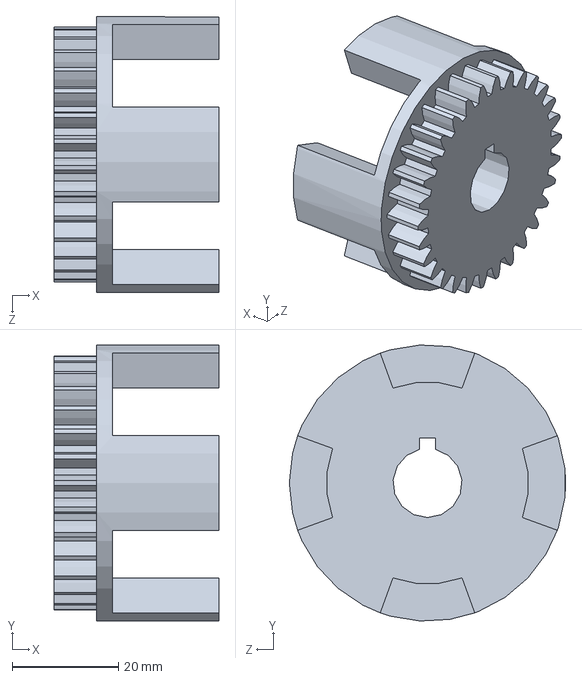
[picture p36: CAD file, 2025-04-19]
assets/狗齿30plus.SLDPRT
31.0 x 51.9 x 52.0 mm

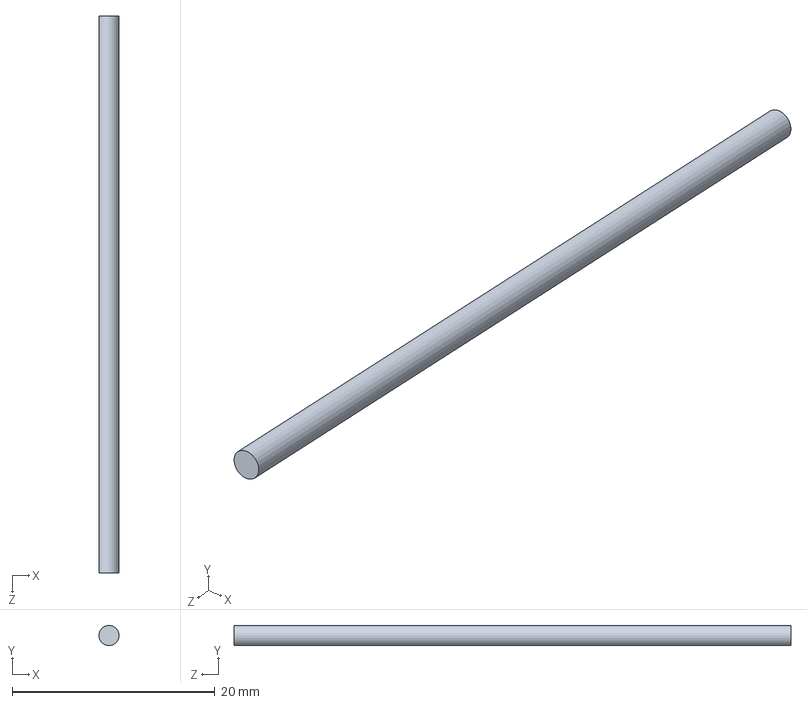
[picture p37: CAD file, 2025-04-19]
assets/临时轴.SLDPRT
2.00 x 2.00 x 55.0 mm

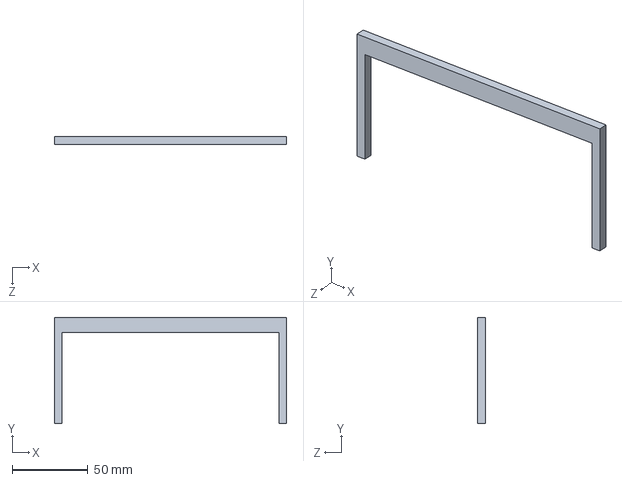
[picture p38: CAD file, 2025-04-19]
assets/拨杆限位.SLDPRT
153.0 x 70.0 x 5.00 mm

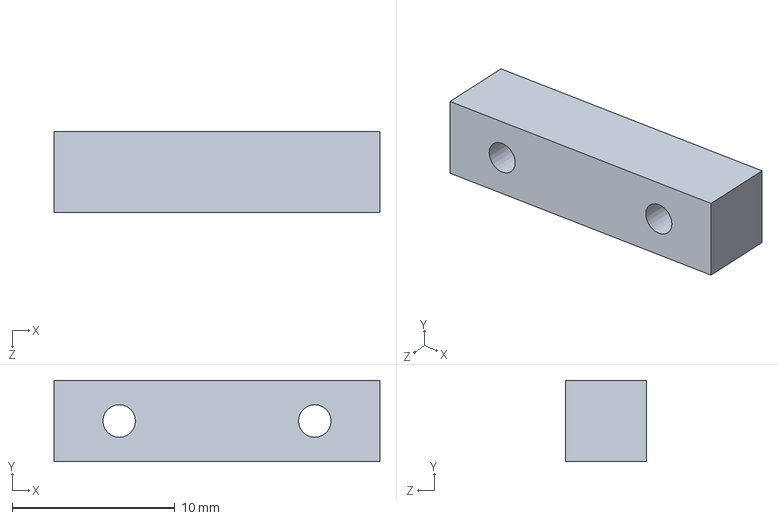
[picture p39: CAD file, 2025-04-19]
assets/临时杆.SLDPRT
20.0 x 5.00 x 5.00 mm

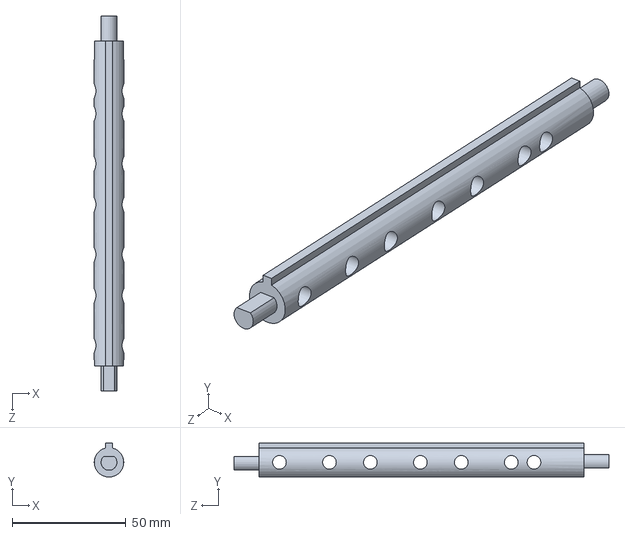
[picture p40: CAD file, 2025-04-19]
assets/zhou.SLDPRT
13.0 x 14.9 x 165.0 mm

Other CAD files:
assets/3D摇杆1.5.STL
assets/狗齿45min.SLDPRT
assets/狗齿30.SLDPRT
assets/zhou2.SLDPRT
assets/3D摇杆.STL
assets/狗齿30plus.STL
assets/狗齿60SLDPRT.SLDPRT
assets/狗齿齿轮30齿.SLDPRT
